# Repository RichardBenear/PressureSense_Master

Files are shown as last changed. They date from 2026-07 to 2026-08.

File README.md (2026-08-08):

# PressureSense

PressureSense_Master is the master controller for an irrigation pressure-monitoring and zone-scheduling system. It runs on a Seeed Studio XIAO ESP32-C6, reads a 0-100 PSI analog pressure sensor, schedules and runs sprinkler zones, and commands a pair of remote relay boards ("Yard" and "Field") over LoRa. A web UI served directly from the ESP32's SPIFFS partition provides live charting, schedule/zone configuration, a sprinkler-system map, and SD/SPIFFS file management. An on-board 3.5" SPI TFT mirrors live status, and a dedicated WebSocket feed drives a separate "Indoor unit" display.

## System overview

- **PressureSense_Master (this repo)** — the scheduler and LoRa master. Decides which zone should be active from the zone table, current pressure, and time of day; reads the pressure sensor; logs data to SD; serves the web UI; and commands the Yard/Field boards over LoRa.
- **Yard / Field remotes** (separate firmware - PressureSense_ValveNode) — dumb relay executors. They accept LoRa relay commands, switch outputs, run their own safety timers, and ACK/ERROR/STATUS back to the master (see [LoRa protocol](#lora-protocol) below).
- **Indoor unit** (separate client - PressureSense_Indoor) — connects to the master's `/ws` WebSocket and consumes the same `sensorUpdate`/`configData` JSON the CHART page uses, for a secondary indoor display (see [WebSocket protocol](#websocket-protocol) below).
- **PressureSense_App** — a Cloudflare Worker + Durable Object that relays that same `/ws` feed to the public internet. It never talks to the master directly; the **Indoor unit** acts as the bridge, holding one outbound connection to the master's local `/ws` and one outbound connection to this Worker's `/device` endpoint, forwarding frames in both directions. This repo has no code running on the master or the Indoor unit — it's purely the cloud side.

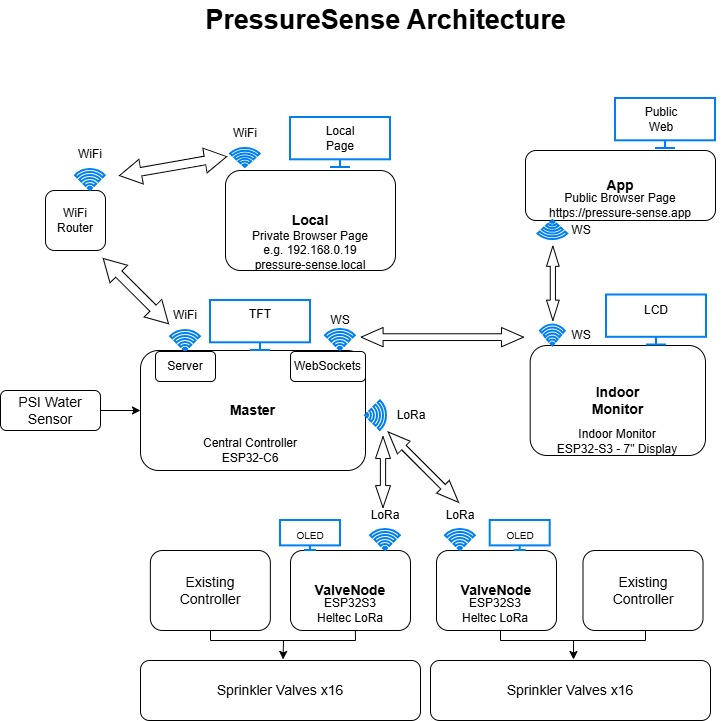
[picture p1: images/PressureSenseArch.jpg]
Architecture Diagram


## Hardware

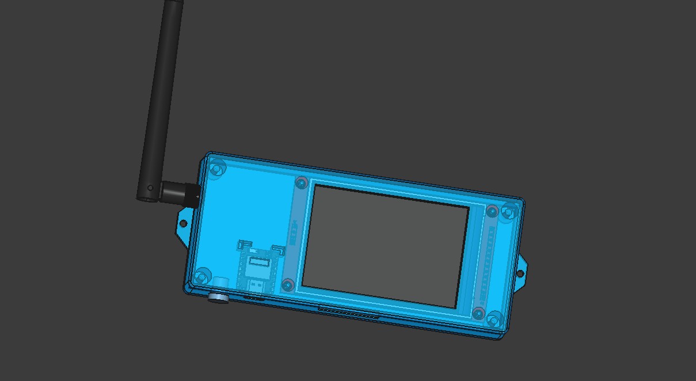
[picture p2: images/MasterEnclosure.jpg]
Enclosure
   
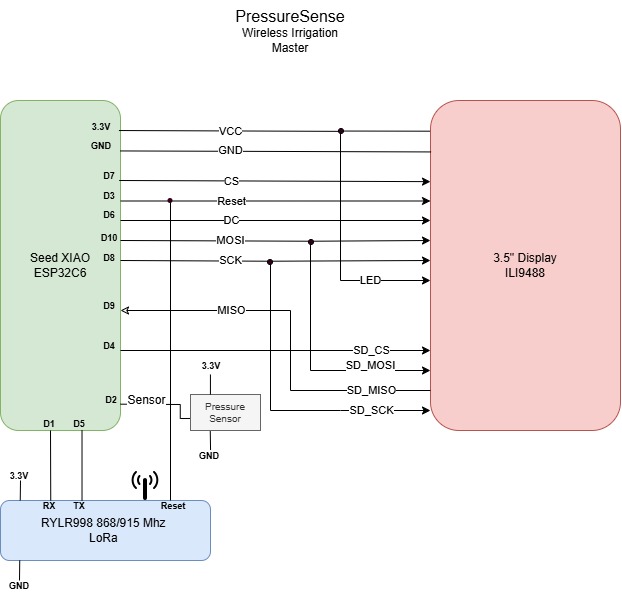
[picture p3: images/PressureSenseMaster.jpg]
Block Diagram
  

| Component | Notes |
| --- | --- |
| MCU | Seeed Studio XIAO ESP32-C6 |
| Pressure sensor | Analog, two-point calibrated (30 PSI @ 1.5V, 60 PSI @ 2.9V), sampled via `analogReadMilliVolts()` |
| Display | 3.5" SPI TFT, ILI9488 driver via LovyanGFX (`src/Display.h`/`.cpp`) |
| LoRa | RYLR998 module on `HardwareSerial1`, AT-command configured at boot |
| Storage | SD card (daily CSV data logs, plus original copies of calibration/weather files kept as a rollback, plus `water_waves.jpg` (background image, manually provisioned)) + SPIFFS (web UI, `site.json`/`controllers.json`, per-zone flow `calibration.json`, `weather_state.json`/`weather_cache.json`/`weather_log.json`, OTA partitions) |
| Enclosure | 3D-printable design in `FreeCAD/` (native `.FCStd` source) |

Pin assignments, sensor calibration constants, and LoRa radio parameters are all `#define`d near the top of [src/main.cpp](src/main.cpp).

## Web UI

Served from SPIFFS at the device's IP, or `http://pressure-sense.local/` via mDNS (Windows PCs need Apple's free [Bonjour Print Services](https://support.apple.com/kb/DL999) installed once for `.local` names to resolve — macOS and iOS support this natively). Five pages share `data/style.css`:

| Page | Files | Purpose |
| --- | --- | --- |
| CHART | `index.html` / `index.js` | Live pressure gauge, OK/WARN/HIGH/LOW status badge, scheduled-zone card, manual zone/program start-stop, a Runtime stat that shows "Wx Adj xx% / Deficit xx.x mm" underneath the active zone's minutes whenever weather auto-adjust is on, Highcharts pressure history (today or any saved day) with an optional ET0/precipitation weather overlay, status bar (location, sample rate, seasonal adjustments, zone delays, calibration offset) |
| CONFIG | `config.html` / `config.js` | Zone schedule editor: per-controller program cards (start time, day pips, duration, end time, overlap warning) with a popover to edit start/days/zone-delay/seasonal-adjustment; zones support drag-to-reorder, inline name/PSI/run editing with live-recalculated start times, add/delete. "Save Zone Config" saves only the schedule (to `controllers.json`, or a named seasonal preset); Location, Sensor Rate, and Weather Auto-Adjust settings each save independently to `site.json`; "Set as Active Schedule" promotes a loaded preset to be the live schedule |
| CALIB | `calibration.html` / `calibration.js` | Per-zone irrigation flow calibration (head specs + SVG-measured area → `mm_per_min`) with an editable Head Catalog, import from the `zone_calibration.py` script's output, and PSI calibration (moved here from CONFIG) |
| MAP | `map.html` / `map.js` | Renders the sprinkler layout SVG, highlights whichever zone(s) are currently active, full-yard or zoomed yard-only view with pan/zoom |
| FILES | `files.html` / `files.js` | Browse/delete SPIFFS and SD card files, preview JSON/text file contents, reboot the ESP32 |

CHART and MAP get live updates over Server-Sent Events at `/events`; the Indoor unit instead uses the JSON WebSocket at `/ws`.

## Key features

- **Zone scheduling** — `controllers.json` (a bare array: controllers → programs → zones) drives automatic activation; see [Zone schedule format](#zone-schedule-format) below.
- **Overlap detection** — the CONFIG page warns when two programs on the same controller share a day and their derived time windows intersect.
- **Manual control** — start/stop an individual zone or an entire lettered program (A-D) outside the schedule, each with its own run timer.
- **Seasonal adjustment** — a per-program percentage (`seasonal_adjust_pct`) that scales that program's scheduled run times up or down.
- **Zone-to-zone delay** — a per-program pause (`zone_delay_sec`) before a chained zone's relay turns on; it shortens that zone's own watering time and never shifts the nominal schedule.
- **Weather auto-adjust** — fetches daily ET0/precipitation from Open-Meteo, tracks a per-zone soil-water deficit, and scales each zone's run time (or skips a program entirely ahead of significant forecast rain) accordingly; enabled/tuned from the CONFIG page, with a 90-day history (`weather_log.json`) chartable on the CHART page.
- **Pressure calibration** — a one-point offset (entered as "actual PSI" against the live raw reading, computed client-side and persisted in `site.json`'s `psi_offset`) layered on top of the two-point factory calibration; set from the CALIB page.
- **Pressure status** — the CHART badge, the chart point colors, and the LoRa master itself (`buildPressureStatus()` in `main.cpp`, kept in sync with `updateStatStatus()` in `index.js`) all classify the live reading against the active zone's target PSI as OK / WARN / HIGH / LOW.
- **Simulation mode** — inject a fixed PSI value in place of the ADC reading, for testing the UI/alerts without water flowing.
- **Data logging** — one CSV per day on the SD card; CHART loads the current day live or any historical day from the file picker.
- **OTA updates** — ElegantOTA, mounted on the same web server.
- **All-off safety** — `ALL_OFF` is sent to both remotes before every zone transition.
- **Pressure vs. schedule state** — zone relay control (`serviceRemoteZoneControl()`), weather auto-adjust's water-applied accumulators, and the deviation alert are all driven by the schedule (`checkActiveZone()`'s `zoneNumber`/`zoneAvgPsi`, and `manualZoneRuns[]` for manual runs), not by pressure. `ZONES_ALL_OFF_PSI`/`currentPressure` only drive the informational `allOff` field broadcast over `/ws` and the TFT gauge's color threshold. (These used to also gate the items above — pressure on this system's tank setup snaps to ~62 PSI on a refill and takes hours to decay back down, so requiring PSI to first drop below `ZONES_ALL_OFF_PSI` could delay, or with a tight enough schedule entirely skip, turning a zone's relay on. Fixed — see git history.)

## Zone schedule format

`data/controllers.json` is the single source of truth for irrigation scheduling — a bare array, read directly by the firmware (`checkActiveZone()` in `main.cpp`) and edited on the CONFIG page. Site identity, sensor rate, PSI calibration, and weather/auto-adjust settings live separately in `data/site.json`; the CONFIG page's `/load-zone-table` endpoint recombines both files into one document for rendering, but they're saved independently (schedule via `/submit-zone-form`, site settings via `/submit-site-form`):

```json
[
  {
    "id": "yard",
    "name": "Yard",
    "programs": [
      {
        "id": "A",
        "days": [0, 1, 2, 3, 4, 5, 6],
        "start": "05:00",
        "zone_delay_sec": 0,
        "seasonal_adjust_pct": 0,
        "zones": [
          { "znumber": 1, "zname": "Garage", "avgpsi": 47, "run": 45 }
        ]
      }
    ]
  }
]
```

`site.json` holds the rest:

```json
{
  "name": "Silver Creek Ranch",
  "sensor_interval_sec": 30,
  "psi_offset": 0.0,
  "latitude": 43.6, "longitude": -116.6, "timezone": "America/Denver",
  "mm_per_min_default": 0.25,
  "weather": { "enabled": true, "auto_adjust": true, "reference_deficit_mm": 6.0, "max_deficit_mm": 25.0, "max_adjust_pct": 150, "min_adjust_pct": 0, "rain_skip_threshold_mm": 6.0 }
}
```

- `days` is an integer array, `0` = Sunday … `6` = Saturday.
- A zone's actual start time is **derived**, never stored: the first zone in a program starts at the program's `start`; every later zone starts when the previous one's `run` ends. `zone_delay_sec` only pauses that zone's relay turn-on — it shortens the zone's own watering time and never shifts this schedule.
- `seasonal_adjust_pct` and `zone_delay_sec` live on the program, not per zone.
- The CONFIG page's "Load External"/"Save As" mechanism supports named schedule presets (e.g. `controllers_spring.json`, `controllers_summer.json`) alongside the live `controllers.json` — "Set as Active Schedule" promotes whichever preset is currently loaded/edited to be the live schedule.

## LoRa protocol

The master and the Yard/Field ValveNode remotes are separate firmware projects (this repo and `PressureSense_ValveNode`) that speak a shared wire protocol over LoRa. This section documents that protocol from the master's side (`initLoRa()`, `sendLoraPacket()`/`sendLoraRelayOn()`, `handleLoraReceiveLine()` in `src/main.cpp`); see `PressureSense_ValveNode/README.md` for the relay-side implementation (RadioLib/SX1262 radio driver, packet CRC verification, per-zone run timers, master-silence watchdog). This repo is the source of truth for the wire format; that repo is the source of truth for how the relay board executes it.

### Radio link

The master uses a **RYLR998** module (AT-command firmware over `HardwareSerial1`, TX/RX on `D5`/`D1`), configured at boot in `initLoRa()`. The ValveNode remotes use a different chip (SX1262 via RadioLib), but both sides are set to the same over-the-air parameters so they can talk to each other:

| Parameter | Value |
| --- | --- |
| Frequency | 915 MHz |
| Spreading factor | 8 |
| Bandwidth | 125 kHz |
| Coding rate | 4/5 |
| Preamble | 8 symbols |
| TX power | 14 dBm |
| Network ID | 18 |

| Node | LoRa address |
| --- | --- |
| Master (this repo) | 10 |
| Yard | 1 |
| Field | 2 |

Outbound packets are sent via the RYLR998's `AT+SEND=<address>,<length>,<hex-payload>` command; inbound packets arrive as `+RCV=<address>,<length>,<hex-payload>,<rssi>,<snr>` lines that `handleLoraReceiveLine()` parses.

### Packet structure

```
[Command/Status] [Relay#/Status] [Flags] [Payload...] [CRC-H] [CRC-L]
      1 byte           1 byte      1 byte    N bytes    1 byte  1 byte
```

The first 3 bytes are a fixed header; everything after is variable-length payload, followed by a 2-byte application-level CRC-16/CCITT (polynomial `0x1021`, initial value `0xFFFF`, computed over every preceding byte) — separate from the LoRa radio's own over-the-air frame integrity check, which the RYLR998/RadioLib handle transparently underneath this.

**Commands (Master → ValveNode)**, sent by `sendLoraPacket()` / `sendLoraRelayOn()`:

| Code | Name | Payload | Relay byte |
| --- | --- | --- | --- |
| 0x01 | RELAY_ON | `minutes` (0-255, 0 = no timer) + `len` + zone name (ASCII, up to 20 chars) | Relay number (1-16) |
| 0x02 | RELAY_OFF | none | Relay number |
| 0x04 | ALL_OFF | none | 0 |
| 0x05 | STATUS_REQUEST | none | 0 |
| 0x06 | RESET | none | 0 |

`ALL_OFF` is sent to both Yard and Field before every scheduled zone transition and when stopping all zones (`sendLoraAllOffToRemotes()`); `RELAY_ON` carries the run-time timer and zone name directly (older 0x03/0x08 follow-up commands are retired).

**Responses (ValveNode → Master)**, handled by `handleLoraReceiveLine()`:

| Code | Name | Payload |
| --- | --- | --- |
| 0x80 | ACK | none |
| 0x81 | ERROR | error code byte |
| 0x82 | STATUS | 2 bytes: relay state bitmask |

The master verifies each response's CRC and logs ACK/ERROR/STATUS to serial for diagnostics — it does not currently retry on a missing ACK or track sequence numbers, so a dropped response is only visible in the serial log, not surfaced to the schedule logic.

**Flags byte:**

| Bit | Name | Meaning |
| --- | --- | --- |
| 0 | `LORA_FLAG_CRC` | Packet includes the trailing CRC-16 (always set) |
| 1 | `LORA_FLAG_RESPONSE_REQUIRED` | Sender expects an ACK/ERROR response (always set) |
| 2 | `LORA_FLAG_TARGET_FIELD` | Yard and Field share one LoRa channel — 0 targets Yard, 1 targets Field. Set automatically from the destination address by `loraFlagsForAddress()`. |
| 3-7 | Reserved | |

### Protocol example

Master turns on relay 3 for 5 minutes, named "Front Lawn", targeting Yard:

```
0x01 0x03 0x03 0x05 0x0A "Front Lawn" 0xXX 0xXX
 cmd  rly flg  min  len     name       CRC-H/L
```

(`flags = 0x03` = `LORA_FLAG_CRC | LORA_FLAG_RESPONSE_REQUIRED`, targeting Yard since bit 2 is 0), sent as `AT+SEND=1,<len>,<hex>`.

ValveNode responds:

```
0x80 0x00 0x03 0xXX 0xXX   // ACK, status 0, relay 3
```

## WebSocket protocol

The master serves one WebSocket endpoint, `/ws`, consumed by two sibling repos: **PressureSense_Indoor** (a touchscreen client with a direct LAN connection) and, through that same Indoor unit acting as a bridge, **PressureSense_App** (a Cloudflare Worker that fans the feed out to remote browsers and relays a narrow set of commands back in — the Worker has no path to the master except through that bridge). This section documents the wire format from the master's side (`buildSensorUpdateJson()`, `buildConfigDataJson()`, `buildManualZoneRunsJson()`, `onWsEvent()` in `src/main.cpp`); see those repos' own READMEs for how each client consumes it and where they deliberately depart from the master's own behavior.

### Server → client messages

Sent via `ws.textAll()` (broadcast to every connected client) or `client->text()` (just the requester), depending on the row below:

| `type` | When sent | Notes |
| --- | --- | --- |
| `sensorUpdate` | Broadcast every sample cycle (`sensorRateSec`); also sent to a client alone right after `WS_EVT_CONNECT` if a reading already exists | Live PSI + active-zone/schedule snapshot — see field reference below |
| `manualZoneStatus` | Broadcast after any `manualZone`/`manualProgram` command changes a run, and every sample cycle | Current manual/program runs — see field reference below. Deliberately kept out of `sensorUpdate` |
| `configData` | To the requester, reply to `getConfig` | `location`, `sampleRateSec`, `calibOffset`, `zones` (the same combined site+controllers document the CONFIG page loads over HTTP — see [Zone schedule format](#zone-schedule-format)) |
| `fileList` | To the requester, reply to `getFiles` | `sdFiles` / `spiffsFiles` arrays |
| `schedule` | To the requester, reply to `getSchedule` | `controllers` — `controllers.json` contents only, never `site.json`/`psi_offset` |
| `schedulesEnabled` | To the requester, reply to `getSchedulesEnabled`; also broadcast to every client after `setSchedulesEnabled` | `enabled` bool |
| `weatherState` | To the requester, reply to `getWeatherState` | Same shape as `GET /weather-state` (firmware-owned runtime deficit/adjust-pct/skip state) plus `type` |
| `weatherLog` | To the requester, reply to `getWeatherLog` | Same shape as `GET /weather_log.json` (`log` array, up to 90 days) plus `type` |
| `weatherCache` | To the requester, reply to `getWeatherCache` | Same shape as `GET /weather_cache.json` (raw Open-Meteo response) plus `type` |
| `calibration` | To the requester, reply to `getCalibration` | Same shape as `GET /calibration.json` (`zones` array) plus `type` |
| `weatherSettings` | To the requester, reply to `getWeatherSettings` | Narrow, read-only subset of `site.json`'s `weather` block (`auto_adjust`, `reference_deficit_mm`, `max_deficit_mm`, `rain_skip_threshold_mm`, `min_adjust_pct`, `max_adjust_pct`, `mm_per_min_default`) — never the full `site.json` |
| `ack` | To the requester, reply to `saveZones`, `deleteFile`, `reset`, `saveSchedule`, `setSchedulesEnabled`, `manualZone`, `manualProgram` | `{cmd, success, message}` (`sendWsAck()`) — `cmd` echoes back which command it's acknowledging |

### Client → server commands

Sent as `{"cmd": "...", ...}`; dispatched in `onWsEvent()`'s `WS_EVT_DATA` case:

| `cmd` | Fields | Effect |
| --- | --- | --- |
| `getConfig` | — | Replies with `configData` |
| `getFiles` | — | Replies with `fileList` |
| `getSchedule` | — | Replies with `schedule` |
| `saveSchedule` | `controllers` | Overwrites `controllers.json` only; acked |
| `getSchedulesEnabled` | — | Replies with `schedulesEnabled` |
| `setSchedulesEnabled` | `enabled` | Pause/resume automatic scheduling; acked to the requester, then `schedulesEnabled` broadcast to all clients |
| `getWeatherState` | — | Replies with `weatherState` |
| `getWeatherLog` | — | Replies with `weatherLog` |
| `getWeatherCache` | — | Replies with `weatherCache` |
| `getCalibration` | — | Replies with `calibration` |
| `getWeatherSettings` | — | Replies with `weatherSettings` |
| `manualZone` | `action` (`start`/`stop`/`stopall`), `controller`, `znumber`, `run` | Start/stop a manual zone run; acked, then `manualZoneStatus` broadcast to all clients |
| `manualProgram` | `action` (`start`/`stop`/`next`), `controller`, `program` | Start/stop/advance a manual lettered-program run; acked, then `manualZoneStatus` broadcast to all clients |
| `saveZones` | `zones: {site, weather, controllers}` | Legacy combined site+controllers save in one command; acked. Not used by the current web UI (which saves over HTTP via `/submit-site-form`/`/submit-zone-form` instead) — kept for any future WS-only client |
| `deleteFile` | `source` (`spiffs`/`sd`), `filename` | Deletes a file; acked |
| `reset` | — | Acks, then reboots the ESP32 |

Only `getSchedule`, `saveSchedule`, `getSchedulesEnabled`, `setSchedulesEnabled`, `manualZone`, `manualProgram`, `getWeatherState`, `getWeatherLog`, `getWeatherCache`, `getCalibration`, and `getWeatherSettings` are ever relayed from a remote browser through PressureSense_App and the Indoor unit back to the master — `getConfig`/`getFiles`/`saveZones`/`deleteFile`/`reset` are only reachable from a client with a direct LAN connection to `/ws`.

### `sensorUpdate` field reference

| Field | Type | Notes |
| --- | --- | --- |
| `psi` | float | Calibrated live pressure (1 decimal) |
| `rawPsi` | float | Pressure before the calibration offset |
| `sampleRateSec` | int | Current sample interval, seconds |
| `adcVoltage` | float | Raw ADC voltage behind the reading (3 decimals) |
| `zoneNumber` | string | Active zone ID; `"0"` means all zones off |
| `zoneName` | string | Active zone's human-readable name |
| `zoneAvgPsi` | float | Active zone's target PSI |
| `status` | string | `OK` / `WARN` / `HIGH` / `LOW`, from `buildPressureStatus()` (mirrors `updateStatStatus()` in `data/index.js`) |
| `controller` | string | `Yard` \| `Field` \| `OFF` |
| `days` | string | Active-days abbreviation, e.g. `"Mo We Fr"`, or `"NONE"` when idle (`formatDaysForDisplay()`) |
| `start` | string | Scheduled start `"HH:MM"`; `"00:00"` means no fixed start |
| `run` | string | Runtime in minutes |
| `remaining` | string | Minutes left in the active run, e.g. `"12m"` (`getZoneRemainingMinutes()`); `""` when not computable |
| `mapKey` | string | `lower(controller):zoneNumber`, e.g. `"yard:3"` (`buildMapKey()`) — matches the MAP page's zone-coverage keys |
| `allOff` | bool | `true` when `currentPressure >= ZONES_ALL_OFF_PSI` (59 PSI) |
| `simMode` | bool | `true` while simulation mode is injecting a synthetic PSI reading |
| `weatherAutoAdjustEnabled` | bool | `site.json`'s `weather.auto_adjust` setting — gates whether `weatherAdjustPct`/`deficitMm` below are meaningful. Also the top-level gate the CHART page's Runtime stat uses to show/hide its "Wx Adj / Deficit" sub-line |
| `weatherAdjustPct` | int | Active zone's live weather adjustment percentage (100 = neutral) — same value already folded into `run` above, surfaced separately so clients can show it alongside the adjusted minutes |
| `deficitMm` | float | Active zone's current soil-water deficit (mm), from `weather_state.json` — diagnostic, shown regardless of `weatherAutoAdjustEnabled`'s effect on scheduling, but the UI only displays it when that flag is true |
| `time` / `date` | string | Wall clock at the master |
| `location` | string | Site label from `site.json` |

**Don't key idle/active-zone logic off `allOff`.** It's only the informational pressure-recovery heuristic described in [Key features](#key-features) above — on this system's pressure-tank setup a refill snaps to ~62 PSI and takes hours to decay back down, so `allOff` reads "not idle" for most of a normal idle cycle. Every downstream client (Indoor, PressureSense_App) keys idle/active-zone state off `zoneNumber`/`controller` (or an empty `manualZoneStatus` runs list) instead — both had this exact bug at one point, found and fixed by auditing every repo for the same `allOff` dependency. Only the master's own PSI gauge color threshold still legitimately uses it.

### `manualZoneStatus` field reference

Sent as `{"type":"manualZoneStatus","weatherAutoAdjustEnabled":bool,"runs":[...]}` (`buildManualZoneRunsJson()`). `weatherAutoAdjustEnabled` is the same site-wide `weather.auto_adjust` flag `sensorUpdate` carries, included here too since this is a separate message a client could receive first. Each entry in `runs`:

| Field | Type | Notes |
| --- | --- | --- |
| `controller` | string | `Yard` / `Field` |
| `relay` | int | Relay/zone number |
| `remainingSec` | int | Seconds left in the current zone's run |
| `totalRunMinutes` | int | That zone's configured run length |
| `program` | bool | `true` if this run is part of a lettered program rather than a single manual zone |
| `programLetter` | string | Program letter (A-D) when `program` is true, else empty |
| `weatherAdjustPct` | int | This zone's live weather adjustment percentage — only meaningful when `program` is true. A manual **zone** run uses exactly the minutes the user picked, bypassing weather adjustment entirely (`startManualZoneRun()`), so this is neutral/100 for those; a manual **program** run replays the schedule's own per-zone adjustment (`findNextProgramZone()`), so it's real here |
| `deficitMm` | float | This zone's current soil-water deficit (mm) — same caveat as `weatherAdjustPct` above |

A run is left out of `runs` while it's paused between zones during a zone-to-zone delay (`delayPending`), not just once it ends.

## Data log format

One row per sample, appended to a daily CSV on the SD card (filename from `generateDailyFilename()`):

```
readingID,date,time,psi,zoneNumber,zoneAvgPsi
```

## HTTP API

All routes are registered in `setup()` in `src/main.cpp`. Static assets (the `data/` folder) are served directly from SPIFFS at `/` — except `/water_waves.jpg`, which is served from the SD card by an explicit route instead (see table below); it was moved out of `data/`/SPIFFS because at 221KB it was consuming a large share of the mostly-full SPIFFS partition.

| Endpoint | Method | Purpose |
| --- | --- | --- |
| `/get-data-file` | GET | Fetch a CSV log file by name |
| `/water_waves.jpg` | GET | Background image for all 5 pages' `body.ag-page::before` CSS layer — served from the SD card (not SPIFFS) via the same locked/chunked pattern as `/get-data-file`; 404s cleanly if the SD card hasn't been provisioned with the file yet |
| `/get-daily-filename` | GET | Current day's log filename |
| `/list-sd-card-files`, `/list-spiffs-files`, `/list-json-files` | GET | File listings for the FILES page |
| `/get-spiffs-json-file` | GET | Read a JSON file from SPIFFS |
| `/delete-file` | GET | Delete a file from SD or SPIFFS |
| `/load-zone-table`, `/load-sd-zone-table` (compat alias), `/load-spiffs-zone-table?filename=` | GET | `site.json` + `controllers.json` recombined into one document for the CONFIG page (see [Zone schedule format](#zone-schedule-format)); `/load-spiffs-zone-table` also serves a named schedule preset or any other SPIFFS `.json` by filename |
| `/submit-zone-form?filename=` | POST | Save only the schedule — to `controllers.json` by default, or a named preset (e.g. `controllers_summer.json`) if `filename` is given |
| `/submit-site-form` | POST | Save site identity, sensor rate, and weather/auto-adjust settings to `site.json` (independent of the schedule save) |
| `/submit-calib-offset` | POST | Save just the PSI calibration offset to `site.json` (CALIB page) |
| `/calibration.json`, `/submit-calibration-form` | GET / POST | Per-zone flow calibration (`mm_per_min`, head specs, SVG area) — CALIB page |
| `/weather-state`, `/weather_cache.json`, `/weather_log.json` | GET | Firmware-computed weather auto-adjust state, the last raw Open-Meteo response, and the 90-day deficit/adjustment history |
| `/weather-fetch-now` | GET | Queue an on-demand weather fetch (runs on the next `loop()` tick, not inline, to avoid blocking the request task) |
| `/get-schedules-enabled`, `/set-schedules-enabled` | GET / POST | Pause / resume automatic scheduling |
| `/manual-zones` | GET | Current manual zone/program run status |
| `/manual-zone`, `/manual-program` | POST | Start/stop a manual zone or lettered program; `/manual-program` also takes `action: "next"` to skip a running program straight to its next zone (or stop it, if the current zone is the last one) |
| `/set-sim-pressure`, `/clear-sim` | GET | Enable / disable simulation mode |
| `/sd-usage` | GET | SD card usage + WiFi/uptime, for page footers |
| `/spiffs-usage` | GET | SPIFFS usage (total/used/free/percent) — added to diagnose SPIFFS filling up and causing save failures; check this before adding any new file to `data/` |
| `/ping` | GET | Lightweight health check: uptime, heap stats, WS client count |
| `/reset` | GET | Reboot the ESP32 |
| `/events` | SSE | Live `new-readings` push for CHART/MAP |
| `/ws` | WebSocket | `sensorUpdate` / `configData` / `manualZoneStatus` JSON feed + command interface for the Indoor unit and (via its relay bridge) PressureSense_App — see [WebSocket protocol](#websocket-protocol) below |

## Getting started

1. **Secrets** — copy `include/secrets.example.h` to `include/secrets.h` and fill in your WiFi SSID/password. `include/secrets.h` is git-ignored.
2. **Build & flash firmware**:
   ```
   pio run --target upload
   ```
3. **Upload the web UI** (everything in `data/`) to SPIFFS:
   ```
   pio run --target uploadfs
   ```
4. **Monitor serial output**:
   ```
   pio device monitor
   ```
5. Visit `http://pressure-sense.local/` (mDNS) or the IP address printed on boot. **Windows users:** `.local` hostnames aren't resolved by Windows out of the box — install Apple's free [Bonjour Print Services](https://support.apple.com/kb/DL999) once, or just use the IP address shown on the TFT/serial log. macOS and iOS resolve `.local` natively, no install needed.

Subsequent firmware updates can go over the air via ElegantOTA at `<device-ip>/update` once the device is reachable on WiFi.

### Boot sequence (serial log markers)

```
[1]  TFT display init
[1b] LoRa radio init (RYLR998 AT config)
[2]  WiFi connect + mDNS (pressure-sense.local)
[3]  SPIFFS mount
[4]  SD card mount
[5]  NTP time sync
[6]  Daily log file + saved location
[7]  Web server + OTA started
```

## Project structure

```
src/main.cpp            Firmware: WiFi/SPIFFS/SD/NTP setup, sensor reads, scheduling,
                         LoRa master protocol, HTTP/WS/SSE server, OTA
src/Display.h/.cpp      LovyanGFX TFT UI (mirrors the web CHART page on-device)
include/secrets.h       WiFi credentials (git-ignored; see secrets.example.h)
data/                   Web UI served from SPIFFS -- index/config/calibration/map/files .html + .js, style.css
data/zone-utils.js      Shared schedule math (derived start/end times, day-array matching,
                         overlap detection) used by both config.js and index.js
data/site.json          Site identity/sensor-rate/calibration/weather config -- checked in as the
data/controllers.json   default seed data so a fresh flash ships a working setup instead of an
                         empty one (see Zone schedule format above); overwritten by whatever you
                         save from the CONFIG page afterward
data/controllers_spring.json   Seasonal schedule presets -- starting points to customize via the
data/controllers_summer.json   CONFIG page's Load External/Save As, then "Set as Active Schedule"
data/controllers_fall.json     to make one live
calib/                  Zone flow calibration tooling: zone_calibration.py's own output
                         (zone_calibration.json/.txt), independent of the device's calibration.json
reference/               Git-tracked copies of files that actually live on the device's SD card
                         or SPIFFS in production, kept here as a safety net since there's no
                         automated way to regenerate/redeploy them (unlike data/ -> SPIFFS via
                         `pio run --target uploadfs`).
reference/weather_log.json     Sample of the 90-day weather deficit/adjustment history.
reference/water_waves.jpg      Background image for style.css's body.ag-page::before layer.
                         NOT in data/ (SPIFFS) -- served from the SD card instead via the
                         /water_waves.jpg route (src/main.cpp), because at 221KB it was the
                         largest single file in data/ and was pushing SPIFFS to ~96% full,
                         which was failing schedule saves. Must be manually copied to the SD
                         card's root as water_waves.jpg after any SD card swap/reformat -- there
                         is no automated deploy path for it. Do not move this file back into
                         data/ without addressing SPIFFS headroom first -- check current usage
                         via GET /spiffs-usage.
scripts/zone_calibration.py     Computes per-zone mm_per_min from head specs + SVG-measured area
scripts/dxf_to_svg.py           Converts a QCAD/AutoCAD DXF sprinkler drawing to SVG for the MAP page
scripts/remove_qcad_trial.py    Strips QCAD trial-version watermark artifacts from exported SVGs
docs/                   Architecture reference diagram (PressureSenseMaster.drawio.png)
FreeCAD/                Enclosure CAD source (enclosure.FCStd)
images/                 Reference photos
platformio.ini          Board/framework/library config (seeed_xiao_esp32c6, Arduino framework)
partitions.csv          Custom partition table (dual OTA app slots + SPIFFS)
```

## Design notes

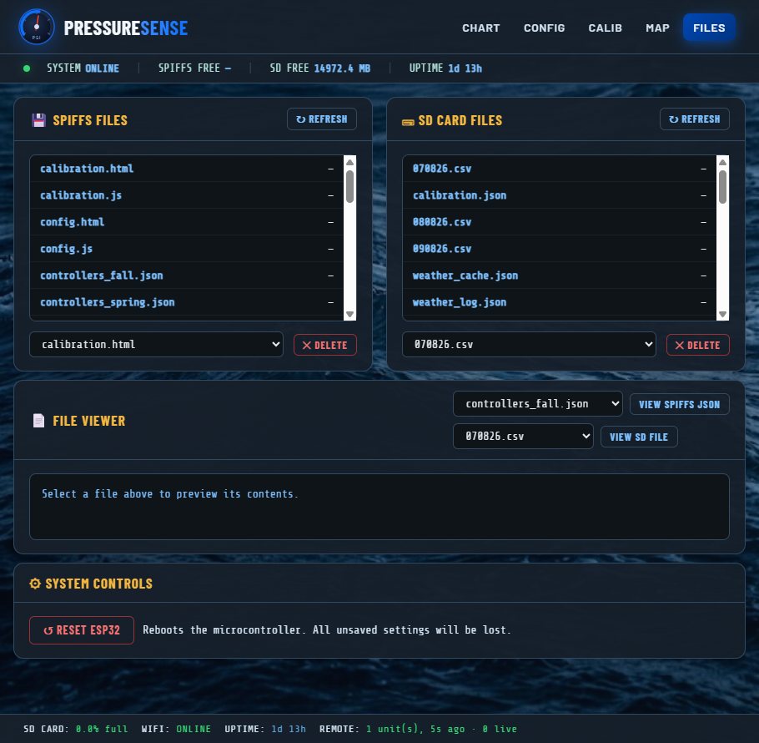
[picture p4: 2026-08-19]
images/PressureSenseFileManagement.jpg

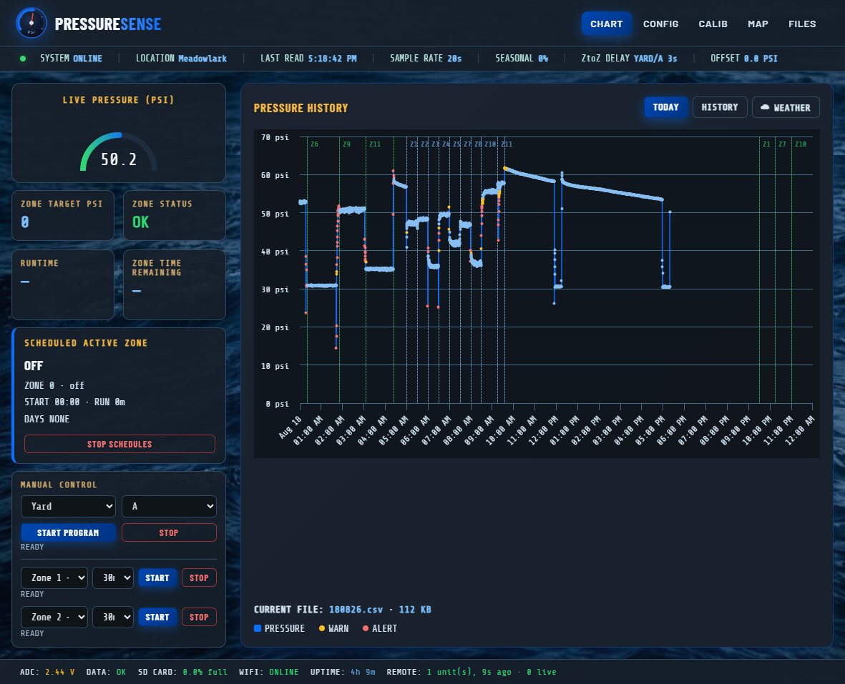
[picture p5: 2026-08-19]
images/PressureSenseChart.jpg

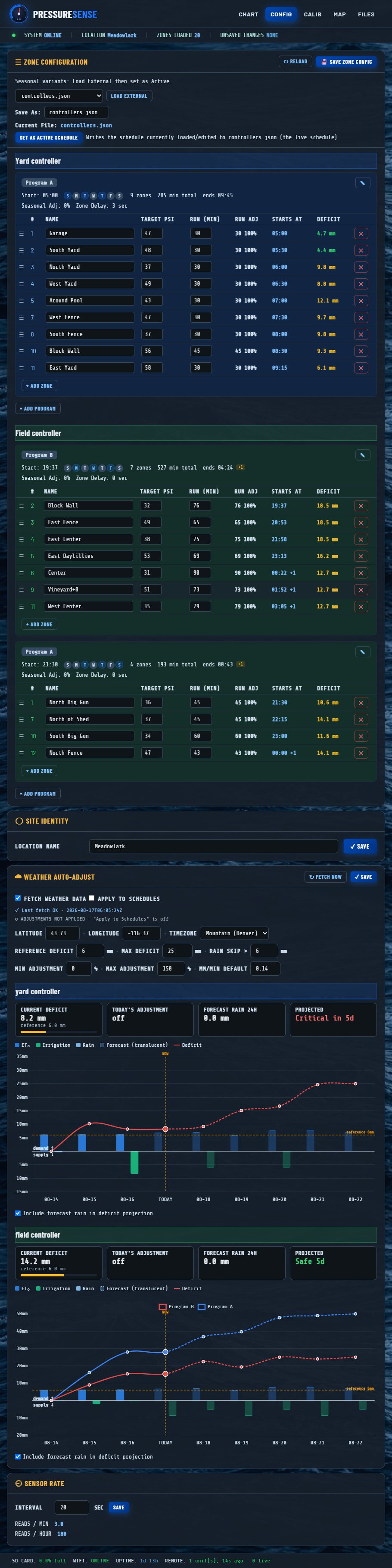
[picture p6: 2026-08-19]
images/PressureSenseConfiguration.jpg

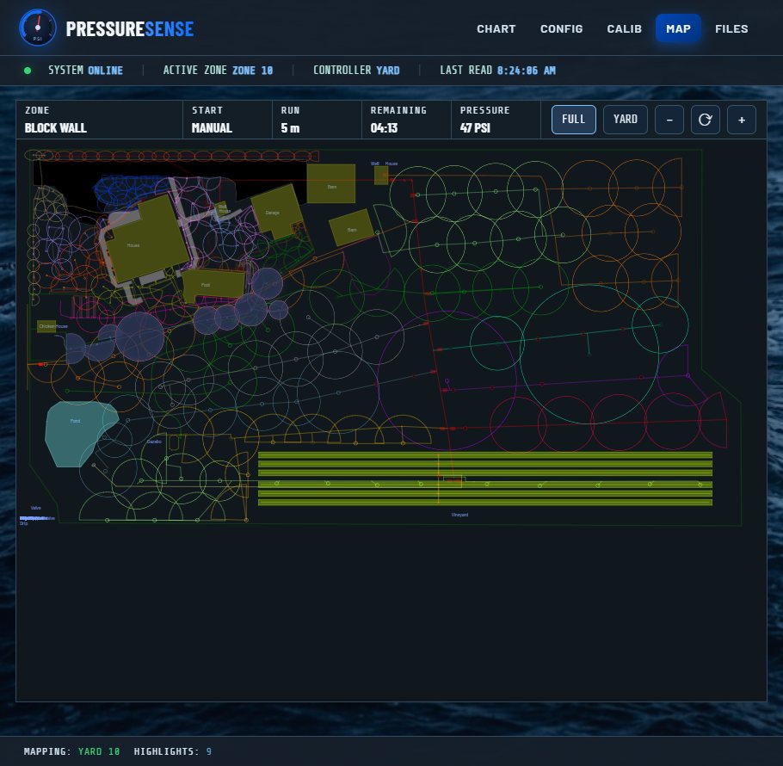
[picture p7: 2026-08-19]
images/PressureSenseZoneMap.jpg

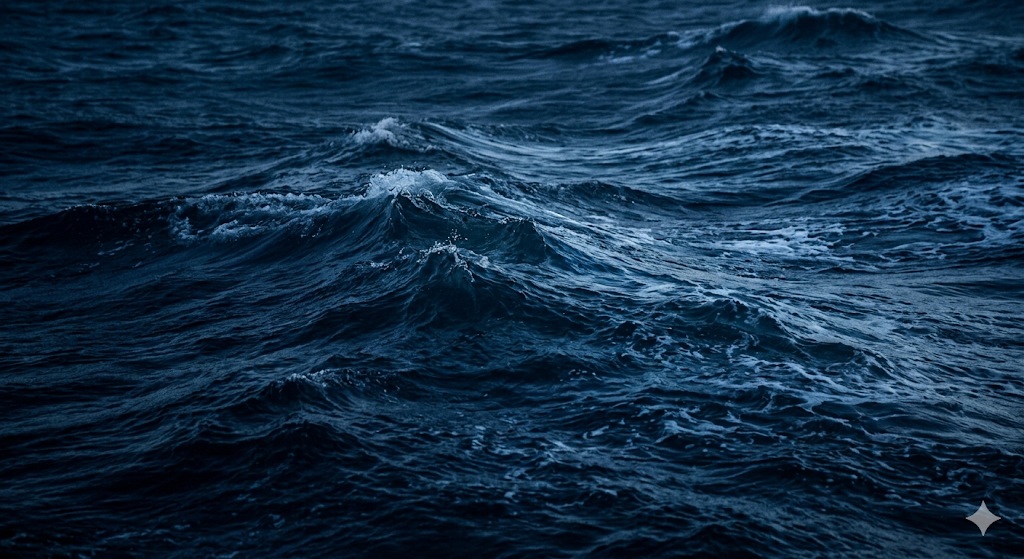
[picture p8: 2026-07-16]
reference/water_waves.jpg

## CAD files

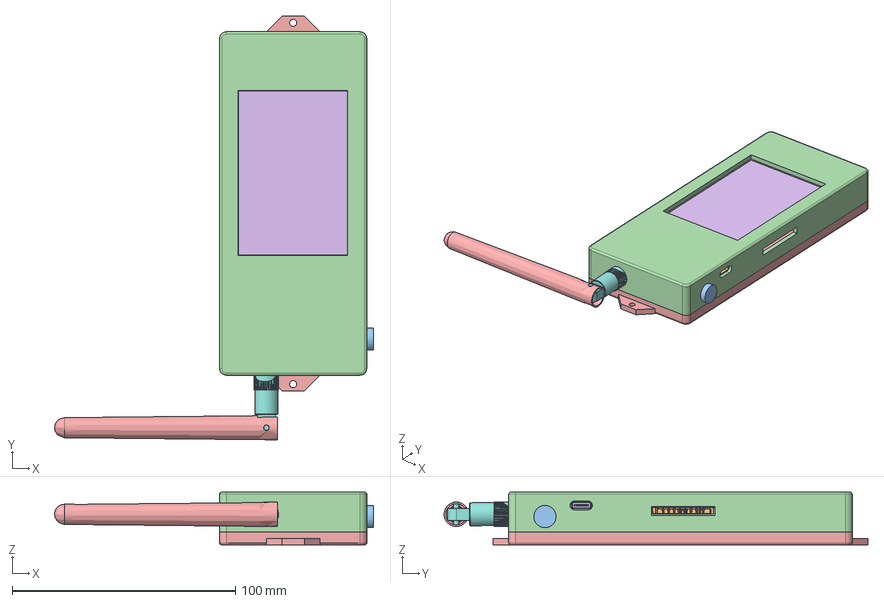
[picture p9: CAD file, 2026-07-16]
FreeCAD/enclosure.FCStd
143.0 x 190.0 x 23.7 mm
3.5 LCD TFT Module - Without Glass
0603 Resistor
0603 Capacitor
3.5 LCD TFT Screen without glass
Screen
0603 Resistor001
0603 Resistor002
0603 Resistor003
0603 Resistor004
SOT23-3
SOT23-004
0603 Resistor005
0603 Capacitor001
0603 Resistor006
BOSS-EXTRUDE14_8_
BOSS-EXTRUDE7_4_
BOSS-EXTRUDE7_3_
BOSS-EXTRUDE14_4_
BOSS-EXTRUDE14_2_
BOSS-EXTRUDE14_11_
BOSS-EXTRUDE7_7_
BOSS-EXTRUDE14_9_
BOSS-EXTRUDE14_3_
BOSS-EXTRUDE14_7_
MIRROR2
BOSS-EXTRUDE14_5_
BOSS-EXTRUDE14_12_
BOSS-EXTRUDE7_8_
BOSS-EXTRUDE7_1_
BOSS-EXTRUDE14_10_
BOSS-EXTRUDE7_9_
BOSS-EXTRUDE14_6_
BOSS-EXTRUDE14_1_
BOSS-EXTRUDE7_6_
BOSS-EXTRUDE7_2_
CUT-EXTRUDE5
BOSS-EXTRUDE7_5_
U.FL Connector v1
U.FL Connector v002
U.FL Connector v003
Shield
SKTAAAE010 v1
SKTAAAE010 v002
KH5220-A36 (Ceramic Antenna) v2
KH5220-A36 (Ceramic Antenna) v003
KH5220-A36 (Ceramic Antenna) v004
KH5220-A36 (Ceramic Antenna) v005
ant
ant001
ant002
conn_body
SMA_threads
socket
PowerJack
Bottom
Lid002

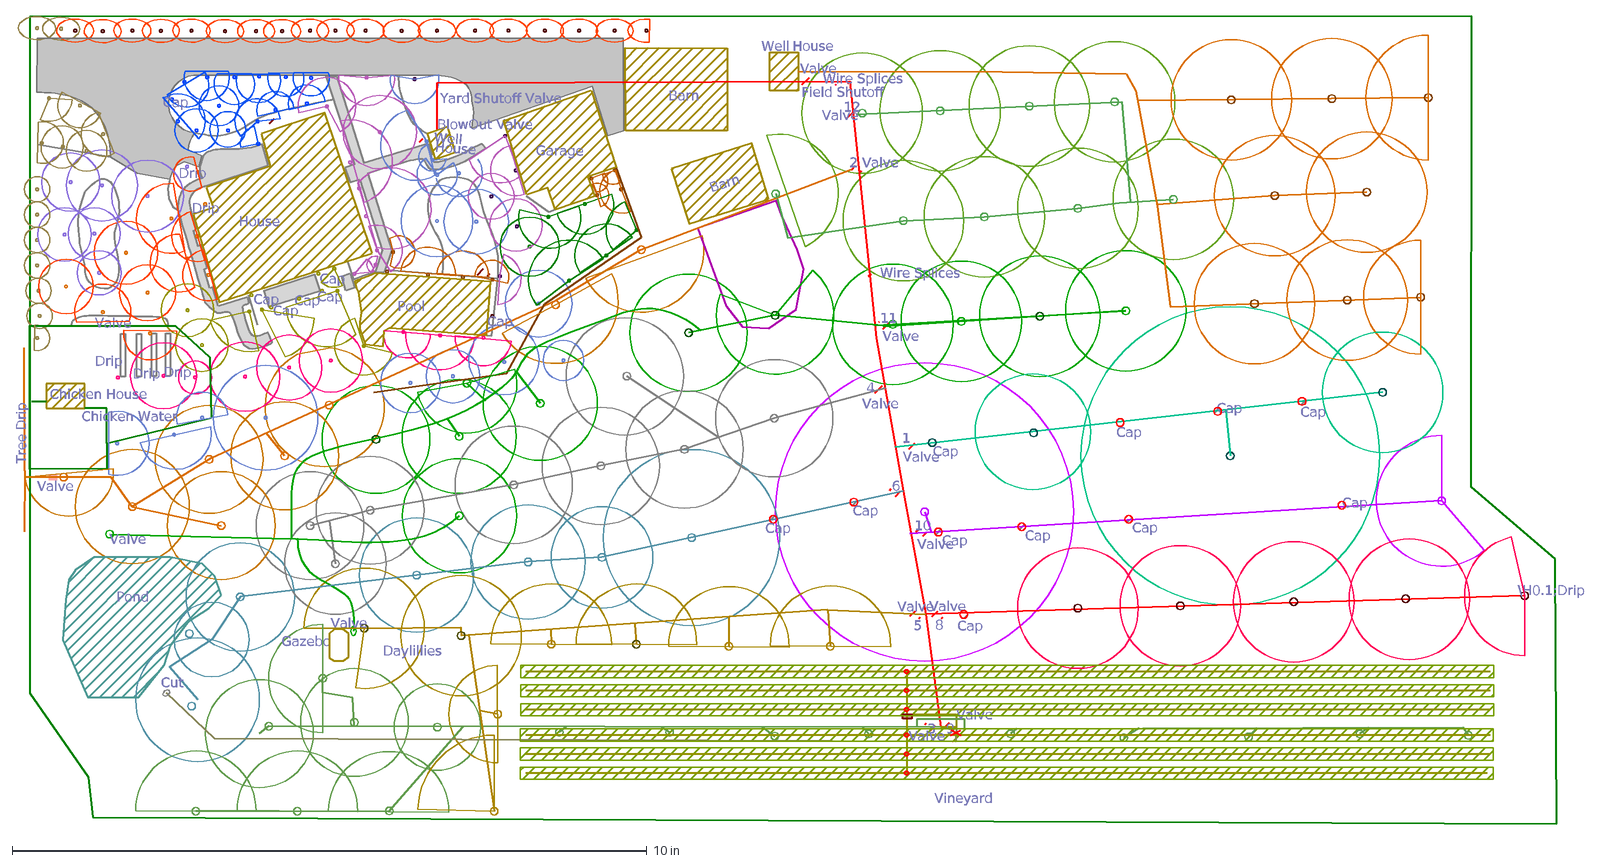
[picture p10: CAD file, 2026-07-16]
images/sprinkler_mapVer8.dxf
House
Pool
Garage
Barn
Chicken House
Pond
Well
Vineyard
Gazebo
Daylillies
Cut
Valve
Field Shutoff
Yard Shutoff Valve
BlowOut Valve
Tree Drip
Wire Splices
\H0.1;Drip
2
12
11
4
1
6
10
5
8
3
9
Cap
Drip
Chicken Water

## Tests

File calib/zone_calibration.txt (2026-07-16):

==================================================================================================================================
                                                   Zone Irrigation Calibration                                                    
                               SVG: ..\images\sprinkler_mapVer8.svg   Scale: 24.01 x 26.03 ft/unit                                
==================================================================================================================================
Ctrl     Zone  Name               Area ft²   Acres    PSI   Flow GPM    mm/min  Head / Emitter          Layers
----------------------------------------------------------------------------------------------------------------------------------
Field       1  North Big Gun        14,263   0.327     36      40.25   0.11497  Big Gun x1              f_cov_1
Field       2  Block Wall            9,704   0.223     32       4.22   0.01770  Rotor x1                f_cov_2
Field       3  East Fence            7,100   0.163     49       5.22   0.02994  Rotor x1                f_cov_3
Field       4  East Center          12,491   0.287     38       4.59   0.01499  Rotor x1                f_cov_4
Field       5  East Daylillies       7,753   0.178     53       5.43   0.02851  Rotor x1                f_cov_5
Field       6  Center               12,201   0.280     31       4.15   0.01386  Rotor x1                f_cov_6
Field       7  North of Shed        14,887   0.342     37       4.53   0.01241  Rotor x1                f_cov_7
Field       9  Vineyard+8           18,743   0.430     51      30.56   0.06643  Drip + Pop-up x5 †      f_cov_8, f_cov_9
Field      10  South Big Gun        12,327   0.283     34      39.12   0.12928  Big Gun x1              f_cov_10
Field      11  West Center          17,018   0.391     35       4.41   0.01056  Rotor x1                f_cov_11
Field      12  North Fence          12,365   0.284     47       5.11   0.01684  Rotor x1                f_cov_12
Yard        1  Garage                2,645   0.061     47       5.11   0.07871  Rotor x1                yd_cov_garage_south, yd_cov_garage_east
Yard        2  South Yard            5,378   0.123     48       5.16   0.03912  Rotor x1                yd_cov_south, yd_cov_se
Yard        3  North Yard            4,562   0.105     37       4.53   0.04049  Rotor x1                yd_cov_well, yd_cov_north
Yard        4  West Yard             1,937   0.044     49       5.22   0.10974  Rotor x1                yd_cov_west
Yard        5  Around Pool           3,599   0.083     43       2.39   0.02710  Pop-up x1               yd_cov_pool_east, yd_cov_pool_west
Yard        7  West Fence            1,892   0.043     47       5.11   0.11004  Rotor x1                yd_cov_west_fence
Yard        8  South Fence           1,603   0.037     37       2.22   0.05645  Pop-up x1               yd_cov_south_fence
Yard       10  Block Wall            4,274   0.098     56       2.73   0.02605  Pop-up x1               yd_cov_blockwall
Yard       11  East Yard             1,337   0.031     58       2.78   0.08475  Pop-up x1               yd_cov_patio
----------------------------------------------------------------------------------------------------------------------------------
  Field total:    138,852 ft²  (3.19 acres)
  Yard total:     27,227 ft²  (0.63 acres)
  Grand total:     166,079 ft²  (3.81 acres)
==================================================================================================================================

Notes:
  Sprinkler flow: flow_gpm = rated_gpm * head_count * sqrt(actual_psi / rated_psi)
  Drip flow (†):  total_gpm specified directly in ZONE_HEAD_ASSIGNMENTS
                  Formula: (line_length_ft / emitter_spacing_ft) * num_lines * emitter_gph / 60
  mm/min:         flow_gpm * 40.74 / area_ft2
  Update head_count or total_gpm in ZONE_HEAD_ASSIGNMENTS and re-run to recalibrate.

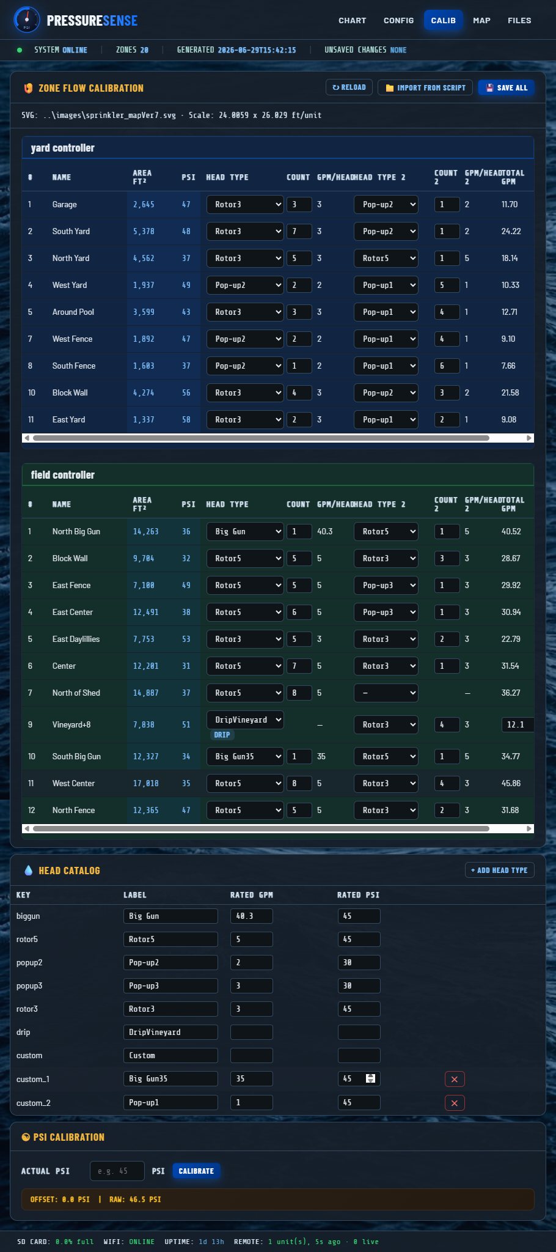
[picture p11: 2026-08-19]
images/PressureSenseCalibration.jpg

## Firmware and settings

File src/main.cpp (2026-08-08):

//*******************************
// Author: Richard Benear 6/7/2026
//*******************************

#include <Arduino.h>
#include "Display.h"
#include <Arduino_JSON.h>
#include <ESPAsyncWebServer.h>
#include <esp_heap_caps.h>
#include <ESPmDNS.h>
#include <ElegantOTA.h>
#include <NTPClient.h>
#include <SPI.h>
#include <WiFi.h>
#include <WiFiUdp.h>
#include <WiFiClientSecure.h>
#include <HTTPClient.h>
#include <time.h>
#include <cmath>	// For fabs()
#include <vector>
#include <map>
#include "FS.h"
#include "SD.h"
#include "secrets.h"
#include "SPIFFS.h"

#define SD_CS D4 				// pin 22	
#define TFT_CS D9 				// pin 20
#define TFT_RST D3 				// pin 21
#define ADC_SAMPLES 10			// number of sensor ADC samples to average
#define SAMPLE_RATE 20000		// PSI sample rate 20 sec in msec
#define ZONES_ALL_OFF_PSI 59	// All Zones off if above this value
#define PRESSURE_WARN_DEVIATION 2.0f	// PSI deviation from zone target to report WARN — matches index.js
#define PRESSURE_ALERT_DEVIATION 4.0f	// PSI deviation from zone target to report HIGH/LOW — matches index.js
#define SENSOR_PIN 2			// Water Pressure sensor on pin GPIO2, ADC, D2
#define TIME_ZONE -3600 * 6		// Mountain Time
#define BUFFER_SIZE 256			// Buffer size for streaming file contents to client in chunks
#define LORA_TX_PIN D5
#define LORA_RX_PIN D1
#define LORA_RESET_PIN TFT_RST
#define LORA_BAUD 115200
#define LORA_MASTER_ADDRESS 10
#define LORA_NETWORK_ID 18
#define LORA_BAND 915000000UL
#define LORA_SPREADING_FACTOR 8
#define LORA_BANDWIDTH 7			// RYLR998 bandwidth code 7 = 125 kHz
#define LORA_CODING_RATE 1			// RYLR998 coding-rate code 1 = 4/5
#define LORA_PREAMBLE 8
#define LORA_TX_POWER_DBM 14
#define LORA_YARD_ADDRESS 1
#define LORA_FIELD_ADDRESS 2

// Since this pressure sensor is designed to run on 5.0 volts but is running
// on 3.3v here, then scale: Pressure Sensor specification:
//    Output 4.5v = 100 PSI
//    Output 0.5v = 0 PSI
//    Slope = 4.0 volts/100 PSI = 0.04 volts/PSI
// Pressure Sensor Scaled:
//    Scaled PSI Range = (3.3v-0.5v)/(5.0v-0.5v) * 100 = 62.2 PSI full range
//    Slope = delta x / delta y: 3.3-0.5-0.5/62.2 = .037 volts/PSI
#define NOMINAL_VOLTS_PER_PSI 0.037
// nominal slope in volts/PSI, based on one point calibration at 48 psi
// measured from analog gauge

// Create AsyncWebServer object on port 80
AsyncWebServer server(80);

// Create an Event Source on /events
AsyncEventSource events("/events");

// Unlike AsyncWebSocket (capped via ws.cleanupClients()), AsyncEventSource
// enforces no client cap at all -- a browser tab that reconnects repeatedly
// (or several tabs/devices left open) can accumulate SSE clients faster
// than the 8s heartbeat's ack-timeout reaps dead ones, eating into the
// device's fixed LWIP socket budget (CONFIG_LWIP_MAX_ACTIVE_TCP = 16) that
// the WS client, HTTP request handling, and outbound weather-API fetches
// all share too. See events.onConnect() below.
#define MAX_SSE_CLIENTS 2  //6
#define MAX_POST_BODY_BYTES 8192
#define HEALTH_LOG_INTERVAL_MS 60000UL

// Create a WebSocket on /ws for the dedicated indoor display
AsyncWebSocket ws("/ws");

HardwareSerial LoRaSerial(1);

// Timer variables
unsigned long lastTime = 0;
unsigned long timerDelay = SAMPLE_RATE;
unsigned long lastSseHeartbeatMillis = 0;

const float adcVoltageScale = 1.032f;
const float sensorCalLowPressure = 30.0f;
const float sensorCalLowVoltage = 1.5f;
const float sensorCalHighPressure = 60.0f;
const float sensorCalHighVoltage = 2.9f;
const float sensorPsiPerVolt = (sensorCalHighPressure - sensorCalLowPressure) /
															 (sensorCalHighVoltage - sensorCalLowVoltage);
const float sensorPressureIntercept = sensorCalLowPressure - (sensorPsiPerVolt * sensorCalLowVoltage);

// Simulation mode — bypasses ADC, injects a fixed PSI value
bool  simMode = false;
float simPsi  = 0.0f;

// variables
float currentPressure = 0.0;
float calibOffset = 0.0;
double ADCvoltage = 0.0;
float rawPressure = 0.0;
int sensorRateSec = 30;
bool schedulesEnabled = true;
String currentLocation  = "";   // cached from site.json's name field, updated on every save
bool   firstReadingDone = false; // guards WS initial-state push on connect

// Set by handleWeatherFetchNow(), consumed by serviceWeatherTask() on its
// next loop() tick -- the actual fetch (a blocking HTTPS call up to 10s)
// must never run directly inside an AsyncWebServer request handler, since
// those execute on the async_tcp task, which IS registered with the 5s
// task watchdog (CONFIG_ESP_TASK_WDT_TIMEOUT_S=5, PANIC=1) and reboots the
// device if a handler blocks past it. Deferring to serviceWeatherTask()
// reuses the same call already proven safe for the daily automatic fetch,
// which runs on loop()'s task instead.
bool weatherFetchNowRequested = false;

bool sdCardLock = false;
unsigned long sdCardLockStartedMillis = 0;

// Last successfully-read SD usage totals, served by /sd-usage whenever
// sdCardLock is held so that handler never touches the SD/SPI bus while a
// logData() write or a /get-data-file stream is mid-transaction elsewhere.
uint64_t cachedSdTotalBytes = 0;
uint64_t cachedSdUsedBytes = 0;

// millis() timestamp of the last periodic ws.textAll(buildSensorUpdateJson())
// broadcast to WS clients (Indoor/Relay units), 0 = none sent yet since boot.
// Surfaced via /sd-usage so the web UI can show remote-unit link health.
unsigned long wsLastBroadcastMillis = 0;
unsigned long lastHealthLogMillis = 0;

// Define NTP Client to get time
WiFiUDP ntpUDP;
NTPClient timeClient(ntpUDP, "pool.ntp.org", TIME_ZONE, 60000);	 // Synchronize time every minute

// Variables to save date and time
String formattedDate = "";
String currentDayStamp = "";
String currentTimeStamp = "";
String currentDailyFilename = "";

IPAddress IPmessage;

static float pressureHistory[CHART_BUFFER_SIZE];
static uint8_t zoneHistory[CHART_BUFFER_SIZE];
static int   historyCount = 0;

// Save reading number on RTC memory
RTC_DATA_ATTR int readingID = 0;

enum LoRaCommand : uint8_t {
	CMD_RELAY_ON = 0x01,
	CMD_RELAY_OFF = 0x02,
	// 0x03 reserved (formerly RUN_TIME, now folded into RELAY_ON)
	CMD_ALL_OFF = 0x04,
	CMD_STATUS_REQUEST = 0x05,
	CMD_RESET = 0x06,
	// 0x08 reserved (formerly ZONE_NAME, now folded into RELAY_ON)
};

enum LoRaResponse : uint8_t {
	RESP_ACK = 0x80,
	RESP_ERROR = 0x81,
	RESP_STATUS = 0x82,
};

static const uint8_t LORA_FLAG_CRC = 0x01;
static const uint8_t LORA_FLAG_RESPONSE_REQUIRED = 0x02;
static const uint8_t LORA_FLAG_TARGET_FIELD = 0x04;
static const uint8_t LORA_ZONE_NAME_MAX_LEN = 20;

String loraLastController = "";
uint8_t loraLastZoneNumber = 0;
bool loraSentIdleAllOff = false;
String loraRxLine = "";

bool zoneDelayPending = false;
unsigned long zoneDelayReadyAt = 0;
int zoneDelayAddress = 0;
uint8_t zoneDelayRelay = 0;
uint16_t zoneDelayRunMinutes = 0;
String zoneDelayController = "";
String zoneDelayName = "";

struct ManualZoneRun {
	bool active;
	String controller;
	uint8_t relay;
	int address;
	unsigned long endMillis;
	uint16_t totalRunMinutes;
	bool isProgram;
	String programLetter;
	int zoneIndex;
	bool delayPending;
	unsigned long delayReadyAt;
	uint8_t pendingRelay;
	int pendingZoneIndex;
	uint16_t pendingRunMinutes;
};

static const uint8_t MAX_MANUAL_ZONE_RUNS = 24;
ManualZoneRun manualZoneRuns[MAX_MANUAL_ZONE_RUNS];

// Weather auto-adjust: how many minutes each (controller,program) has
// actually run today, accumulated once per sample tick in loop(). There is
// no existing per-run duration log to derive this from after the fact (only
// a per-sample CSV row) -- see the implementation plan's water-applied gap.
// RAM-only; consumed and reset to zero by serviceWeatherTask() at day
// rollover. A mid-day reboot loses partial-day accumulation -- accepted,
// low-impact, self-correcting limitation.
// Keyed per-zone (not per-program) so fetchAndApplyWeatherUpdate() can apply
// each zone's own calibrated mm_per_min (calibration.json) to its own
// minutes, rather than one blanket site-wide rate -- the whole point of the
// zone calibration feature. zone.number is already read every sample for
// the display, so no Display.h/Display.cpp change is needed to get it here.
struct WaterAppliedAccumulator {
	String controller;
	int zoneNumber;
	float minutesAppliedToday;
};
static const uint8_t MAX_WEATHER_ZONE_SLOTS = 32;	// generous headroom above the current real zone count (~20)
WaterAppliedAccumulator waterAppliedAccumulators[MAX_WEATHER_ZONE_SLOTS];

// One night's computed result for a single zone -- the new source of truth
// for the weather budget (see weather_state.json's "zones" array). Replaces
// the old single site-wide deficit/adjustPct: each zone's own deficit is
// driven by the shared ET0/rain plus its own applied water, never combined
// with other zones' depths (different zones water different physical areas,
// so their mm values aren't addable -- see the implementation plan).
struct ZoneWeatherResult {
	String controller;
	String program;	// which program this zone belongs to -- carried through only for the program-level log aggregate below
	int zoneNumber;
	double deficitMm;
	int weatherAdjustPct;
	double appliedMm;	// that zone's own applied depth last night -- carried through only for the controller/program-level log aggregates below
};

// weather_log.json's per-day history stays at controller granularity (not
// per-zone -- would balloon the 90-day log for no benefit, since the only
// consumer is the chart's coarse "past 5 days" bars). deficitMm/appliedMm
// are area-weighted averages of that controller's zones (still depths, so
// area-weighting applies); adjustPct is a plain mean (a dimensionless
// ratio, not a depth -- area-weighting doesn't apply to it).
struct ControllerLogAggregate {
	String controller;
	double deficitMm;
	double appliedMm;
	int adjustPct;
};

// Same area-weighted/plain-mean pattern as ControllerLogAggregate, but keyed
// by (controller, program) -- a controller's programs can water disjoint
// physical areas (e.g. field's program A/B split), so each program's
// deficit/applied history must stay independent rather than being blended
// into the controller's single number. Logged nested inside each
// controller's weather_log.json entry (see appendWeatherLogRecord).
struct ProgramLogAggregate {
	String controller;
	String program;
	double deficitMm;
	double appliedMm;
	int adjustPct;
};

String lookupZoneName(String controller, uint8_t relay);
String lookupZoneProgram(String controller, uint8_t relay);
String loadSite();
bool saveSite(JSONVar siteVar);
String loadControllers();
bool saveControllers(JSONVar controllersVar, String filename = "controllers.json");
JSONVar buildSiteVarFromParts(JSONVar siteFields, JSONVar weatherFields);
String buildCombinedZoneDocJson();
int applyRunAdjustments(int baseRunMinutes, int seasonalPct, int weatherPct);
int lookupZoneDelaySeconds(String controller, String program);
int lookupZoneWeatherAdjustPct(String controller, int zoneNumber);
bool isWeatherAutoAdjustEnabled();
double lookupZoneDeficitMm(String controller, int zoneNumber);
bool consumeSkipNextRun(String controller, String program);
String loadWeatherState();
String loadCalibrationData();
String appendWsTypeField(String json, const String &extraFields);
double lookupZoneAreaFt2(String controller, int zoneNumber);
double lookupZoneMmPerMin(String controller, int zoneNumber);
double jsonNumberOr(JSONVar parent, const char *key, double fallback);
String jsonStringOr(JSONVar parent, const char *key, String fallback);
bool jsonBoolOr(JSONVar parent, const char *key, bool fallback);

uint16_t crc16Ccitt(const uint8_t *data, size_t length) {
	uint16_t crc = 0xFFFF;
	for (size_t i = 0; i < length; i++) {
		crc ^= (uint16_t)data[i] << 8;
		for (uint8_t bit = 0; bit < 8; bit++) {
			crc = (crc & 0x8000) ? (crc << 1) ^ 0x1021 : crc << 1;
		}
	}
	return crc;
}

String bytesToHex(const uint8_t *data, size_t length) {
	const char hexDigits[] = "0123456789ABCDEF";
	String out = "";
	out.reserve(length * 2);
	for (size_t i = 0; i < length; i++) {
		out += hexDigits[(data[i] >> 4) & 0x0F];
		out += hexDigits[data[i] & 0x0F];
	}
	return out;
}

int hexNibble(char c) {
	if (c >= '0' && c <= '9') return c - '0';
	if (c >= 'A' && c <= 'F') return c - 'A' + 10;
	if (c >= 'a' && c <= 'f') return c - 'a' + 10;
	return -1;
}

bool hexToBytes(const String &hex, uint8_t *out, size_t maxLength, size_t &outLength) {
	outLength = 0;
	if ((hex.length() % 2) != 0) return false;
	if ((size_t)(hex.length() / 2) > maxLength) return false;

	for (int i = 0; i < hex.length(); i += 2) {
		int high = hexNibble(hex.charAt(i));
		int low = hexNibble(hex.charAt(i + 1));
		if (high < 0 || low < 0) return false;
		out[outLength++] = (uint8_t)((high << 4) | low);
	}
	return true;
}

bool verifyPacketCrc(const uint8_t *packet, size_t length) {
	if (length < 5) return false;
	uint16_t expected = ((uint16_t)packet[length - 2] << 8) | packet[length - 1];
	return crc16Ccitt(packet, length - 2) == expected;
}

void loraSendRawCommand(const String &command, uint16_t settleMs = 120) {
	LoRaSerial.print(command);
	LoRaSerial.print("\r\n");
	Serial.println("[LoRa] > " + command);
	delay(settleMs);
}

void initLoRa() {
	LoRaSerial.begin(LORA_BAUD, SERIAL_8N1, LORA_RX_PIN, LORA_TX_PIN);
	delay(150);

	loraSendRawCommand("AT");
	loraSendRawCommand("AT+ADDRESS=" + String(LORA_MASTER_ADDRESS));
	loraSendRawCommand("AT+NETWORKID=" + String(LORA_NETWORK_ID));
	loraSendRawCommand("AT+BAND=" + String(LORA_BAND));
	loraSendRawCommand("AT+PARAMETER=" + String(LORA_SPREADING_FACTOR) + "," +
	                   String(LORA_BANDWIDTH) + "," +
	                   String(LORA_CODING_RATE) + "," +
	                   String(LORA_PREAMBLE));
	loraSendRawCommand("AT+CRFOP=" + String(LORA_TX_POWER_DBM));
	Serial.println("[LoRa] RYLR998 serial initialized");
}

int loraAddressForController(String controller) {
	controller.trim();
	controller.toLowerCase();
	if (controller == "yard") return LORA_YARD_ADDRESS;
	if (controller == "field") return LORA_FIELD_ADDRESS;
	return -1;
}

const char *loraCommandName(uint8_t command) {
	switch (command) {
		case CMD_RELAY_ON: return "RELAY_ON";
		case CMD_RELAY_OFF: return "RELAY_OFF";
		case CMD_ALL_OFF: return "ALL_OFF";
		case CMD_STATUS_REQUEST: return "STATUS_REQUEST";
		case CMD_RESET: return "RESET";
		default: return "UNKNOWN";
	}
}

uint8_t loraFlagsForAddress(int address, uint8_t flags) {
	if (address == LORA_FIELD_ADDRESS) flags |= LORA_FLAG_TARGET_FIELD;
	return flags;
}

bool sendLoraPacket(int address, uint8_t command, uint8_t relay, uint8_t flags = LORA_FLAG_CRC | LORA_FLAG_RESPONSE_REQUIRED) {
	if (address <= 0) return false;

	uint8_t packet[5];
	packet[0] = command;
	packet[1] = relay;
	packet[2] = loraFlagsForAddress(address, flags);
	uint16_t crc = crc16Ccitt(packet, 3);
	packet[3] = (uint8_t)(crc >> 8);
	packet[4] = (uint8_t)(crc & 0xFF);

	String payload = bytesToHex(packet, sizeof(packet));
	String at = "AT+SEND=" + String(address) + "," + String(payload.length()) + "," + payload;
	loraSendRawCommand(at);
	Serial.printf("[LoRa] sent %s relay %u to addr %d payload %s\n",
	              loraCommandName(command), relay, address, payload.c_str());
	return true;
}
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
void loop() {
	serviceWiFi();
	ElegantOTA.loop();
	ws.cleanupClients();
	pollLoRaResponses();
	serviceManualZoneRuns();
	serviceZoneDelayTimers();
	serviceSdCardLockWatchdog();
	serviceWeatherTask();

	// A dead /events (SSE) client -- e.g. a browser tab whose TCP connection
	// died silently over a sleep/wake cycle -- only gets pruned by AsyncTCP's
	// ~5s ack-timeout on the next time the server actually tries to write to
	// it. Left to the timerDelay-gated sensor broadcast below, that's up to
	// sensorRateSec (often 30s+) between opportunities, letting stale
	// connections pile up during a long idle session against the device's
	// limited concurrent-TCP-connection budget. This fixed, short interval
	// bounds how long a dead connection can sit before being reaped,
	// independent of sensorRateSec.
	if (millis() - lastSseHeartbeatMillis >= 8000) {
		lastSseHeartbeatMillis = millis();
		events.send("hb", "heartbeat", millis());
	}

	if (millis() - lastHealthLogMillis >= HEALTH_LOG_INTERVAL_MS) {
		lastHealthLogMillis = millis();
		Serial.printf(
			"[HEALTH] free=%u min=%u maxAlloc=%u largest=%u WS=%u SSE=%u RSSI=%d sdLock=%d\n",
			ESP.getFreeHeap(),
			ESP.getMinFreeHeap(),
			ESP.getMaxAllocHeap(),
			heap_caps_get_largest_free_block(MALLOC_CAP_8BIT),
			ws.count(),
			events.count(),
			WiFi.RSSI(),
			sdCardLock ? 1 : 0
		);
	}

	if ((millis() - lastTime) > timerDelay) {
		lastTime = millis();

		// Check if it's time to update the daily filename
		updateDailyFilename();

		// Send Events to the client with the Sensor Readings Every 30 seconds
		// events.send("ping", NULL, millis());
		events.send(getSensorReading().c_str(), "new-readings", millis());

		// Broadcast the same reading to all WebSocket clients (indoor display)
		firstReadingDone = true;
		ws.textAll(buildSensorUpdateJson());
		wsLastBroadcastMillis = millis();
		// Manual runs live in a separate mechanism from checkActiveZone() and
		// never appear in sensorUpdate. Broadcast their state on the same
		// cadence so late-joining viewers and natural run-expiry stay in sync.
		ws.textAll(buildManualZoneRunsJson());

		// Build zone info for the display
		ZoneInfo zone;
		zone.number     = String((const char *)readingsJson["Active Zone"]["znumber"]);
		zone.name       = String((const char *)readingsJson["Active Zone"]["zname"]);
		zone.controller = String((const char *)readingsJson["Active Zone"]["controller"]);
		zone.days       = String((const char *)readingsJson["Active Zone"]["days"]);
		zone.start      = String((const char *)readingsJson["Active Zone"]["start"]);
		zone.run        = String((const char *)readingsJson["Active Zone"]["run"]);
		zone.avgPsi     = String((const char *)readingsJson["Active Zone"]["avgpsi"]).toFloat();
		zone.allOff     = (currentPressure >= ZONES_ALL_OFF_PSI);

		// zone.number directly, not gated on zone.allOff -- see the comment
		// in serviceRemoteZoneControl() for why the pressure heuristic can't
		// be trusted to reflect the schedule promptly.
		uint8_t currentZoneNumber = (uint8_t)zone.number.toInt();
		serviceRemoteZoneControl(zone);

		// Weather auto-adjust: accumulate today's actual watering minutes per
		// zone (not program -- see WaterAppliedAccumulator). Schedule-gated
		// only (controller present and not "off") -- previously also gated
		// on the pressure-confirmed allOff heuristic, but that reads "not
		// flowing" for a while after a zone starts whenever pressure hasn't
		// yet fallen from a recent refill, which would undercount real
		// watering during that window.
		if (zone.controller.length() > 0 && zone.controller != "off") {
			int waterSlot = findOrCreateWaterAccumulatorSlot(zone.controller, (int)currentZoneNumber);
			if (waterSlot >= 0) {
				waterAppliedAccumulators[waterSlot].minutesAppliedToday += sensorRateSec / 60.0f;
			}
		}

		// Weather auto-adjust: same per-tick crediting as the scheduled path
		// above, but for Manual Program runs -- manualZoneRuns[] is populated
		// by startManualProgramRun()/serviceManualZoneRuns() and never known to
		// checkActiveZone(), so it needs its own loop here rather than being
		// folded into the block above. Gated on manualZoneRuns[].active/
		// isProgram/delayPending directly (relay-commanded state), not the
		// site-wide pressure sensor -- same reasoning as the scheduled path.
		// Ad hoc single-zone manual runs (isProgram == false) are
		// intentionally excluded -- out of scope for this feature.
		for (uint8_t i = 0; i < MAX_MANUAL_ZONE_RUNS; i++) {
			if (!manualZoneRuns[i].active || !manualZoneRuns[i].isProgram) continue;
			if (manualZoneRuns[i].delayPending) continue; // relay is physically off during the inter-zone gap

			int waterSlot = findOrCreateWaterAccumulatorSlot(manualZoneRuns[i].controller, (int)manualZoneRuns[i].relay);
			if (waterSlot >= 0) {
				waterAppliedAccumulators[waterSlot].minutesAppliedToday += sensorRateSec / 60.0f;
			}
		}

		// Rolling display history — shift left when full, append newest sample.
		if (historyCount < CHART_BUFFER_SIZE) {
			pressureHistory[historyCount] = currentPressure;
			zoneHistory[historyCount] = currentZoneNumber;
			historyCount++;
		} else {
			memmove(pressureHistory, pressureHistory + 1,
			        (CHART_BUFFER_SIZE - 1) * sizeof(float));
			memmove(zoneHistory, zoneHistory + 1,
			        (CHART_BUFFER_SIZE - 1) * sizeof(uint8_t));
			pressureHistory[CHART_BUFFER_SIZE - 1] = currentPressure;
			zoneHistory[CHART_BUFFER_SIZE - 1] = currentZoneNumber;
		}

		// Alert when live PSI is >4 below the zone's configured average.
		// zone.avgPsi > 0 already implies an active zone (checkActiveZone()
		// only populates it for the schedule's current zone) -- dropped the
		// !zone.allOff gate, which could suppress a real deviation right as
		// a zone starts, before pressure has fallen from a recent refill.
		String alertZoneName = "";
		if (zone.avgPsi > 0.0f && currentPressure < zone.avgPsi - PRESSURE_ALERT_DEVIATION) {
			alertZoneName = zone.name;
		}

		getTimeStamp(currentDayStamp, currentTimeStamp);
		updateTftDisplay(currentPressure, IPmessage, WiFi.RSSI(), zone,
		                 currentTimeStamp, pressureHistory, zoneHistory, historyCount,
		                 (int)(timerDelay / 1000), alertZoneName);
		logData();
		Serial.println(ADCvoltage);
	}
	delay(100);
}

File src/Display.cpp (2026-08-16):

#include "Display.h"
#include <cmath>   // fabsf, roundf

// ── LovyanGFX hardware config ─────────────────────────────────────────────────

class LGFX : public lgfx::LGFX_Device {
    lgfx::Panel_ILI9488 _panel;
    lgfx::Bus_SPI       _bus;

public:
    LGFX(void) {
        {
            auto cfg = _bus.config();
            cfg.spi_host    = SPI2_HOST;
            cfg.spi_mode    = 0;
            cfg.freq_write  = 8000000;
            cfg.freq_read   = 4000000;
            cfg.spi_3wire   = false;
            cfg.use_lock    = true;
            cfg.dma_channel = SPI_DMA_CH_AUTO;
            cfg.pin_sclk    = 19;   // D8
            cfg.pin_mosi    = 18;   // D10
            cfg.pin_miso    = 20;   // D9  (readable = false)
            cfg.pin_dc      = 16;   // D6
            _bus.config(cfg);
            _panel.setBus(&_bus);
        }
        {
            auto cfg = _panel.config();
            cfg.pin_cs       = 17;   // D7
            cfg.pin_rst      = 21;   // D3
            cfg.pin_busy     = -1;
            cfg.panel_width  = 320;
            cfg.panel_height = 480;
            cfg.readable     = false;
            cfg.invert       = false;
            cfg.rgb_order    = false;
            cfg.dlen_16bit   = false;
            cfg.bus_shared   = true;
            _panel.config(cfg);
        }
        setPanel(&_panel);
    }
};

static LGFX tft;

// ── Color palette (RGB565) — mirrors the web UI CSS variables ─────────────────
// Updated alongside the site-wide contrast & typography pass (brighter
// secondary text, amber section headings, brighter status colors) so the
// on-device panel and the web dashboard read as the same product.
//
//  Web hex    →  R5  G6  B5  → RGB565
//  #060a10   →   0   2   2  → 0x0042   body background
//  #0d1117   →   1   4   2  → 0x0882   header / card background
//  #0a1420   →   1   5   4  → 0x0924   gauge panel background  (NEW)
//  #061420   →   0   5   4  → 0x0124   zone card background    (NEW)
//  #0d1a2a   →   1   6   5  → 0x08C5   stat card background    (NEW)
//  #3f658d   →   8  25  17  → 0x4331   borders, grid lines
//  #9eb3c4   →  19  44  24  → 0x9D98   dim labels                   (was #546c81)
//  #7ec1ff   →  15  48  31  → 0x7E1F   mid values / meta text       (was #60a5fa/#87bef2)
//  #f2f7fc   →  30  61  31  → 0xF7BF   primary value text           (was #e8f4fd)
//  #0d6efd   →   1  27  31  → 0x0B7F   accent blue
//  #f4b740   →  30  45   8  → 0xF5A8   section headings (amber)     (was #c7c419 yellow-green)
//  #fbbf24   →  31  47   4  → 0xFDE4   amber / warning               (was #f59e0b)
//  #10ce42   →   2  22   5  → 0x1668   green / OK
//  #f87171   →  31  28  14  → 0xFB8E   red / error                   (was #ef4444)
//  #1a1200   →   3   9   0  → 0x1900   amber pill background   (NEW)
//  #0a2a1a   →   1  10   3  → 0x0943   status OK pill bg       (NEW)
//  #2a0a0a   →   5   2   1  → 0x2801   status ERR pill bg      (NEW)
//  #1a1500   →   3  10   0  → 0x1A00   status WARN pill bg     (NEW)

static const uint16_t C_BG_BODY   = 0x0042;
static const uint16_t C_BG_HEADER = 0x0882;
static const uint16_t C_BG_GAUGE  = 0x0924;   // gauge panel — blue-tinted dark
static const uint16_t C_BG_ZONE   = 0x0124;   // zone card  — deeper blue-green
static const uint16_t C_BG_STAT   = 0x08C5;   // mini stat cards
static const uint16_t C_BORDER    = 0x4331;
static const uint16_t C_DIM       = 0x9D98;
static const uint16_t C_BLUE_HI   = 0x7E1F;
static const uint16_t C_HI        = 0xF7BF;
static const uint16_t C_HEAD      = 0xF5A8;
static const uint16_t C_ACCENT    = 0x0B7F;
static const uint16_t C_AMBER     = 0xFDE4;
static const uint16_t C_RED       = 0xFB8E;
static const uint16_t C_GREEN     = 0x1668;
static const uint16_t C_AMBER_BG  = 0x1900;   // pill bg for amber alerts
static const uint16_t C_OK_BG     = 0x0943;   // pill bg for OK status
static const uint16_t C_ERR_BG    = 0x2801;   // pill bg for ERR status
static const uint16_t C_WARN_BG   = 0x1A00;   // pill bg for WARN status

// ── Layout (480 × 320, landscape rotation) ────────────────────────────────────
//
//  y=0..31    : header bar
//  y=32       : horizontal separator
//  y=33..157  : gauge panel      (C_BG_GAUGE)
//  y=158..196 : stat card row    (two mini cards, C_BG_STAT)
//  y=197..286 : zone info card   (C_BG_ZONE)
//  y=287..319 : today strip      (C_BG_HEADER)
//
//  x=0..151   : left panel
//  x=152      : vertical separator
//  x=153..178 : Y-axis label column  (26 px)
//  x=179      : Y-axis line
//  x=180..474 : chart data area      (295 px, 5 px right gutter)
//  y=285      : X-axis line
//  y=286..319 : time label / today strip row

static const int HDR_H     = 32;
static const int LPANEL_W  = 152;
static const int SEP_X     = 152;
static const int YAXIS_X   = 179;
static const int PLOT_X    = 180;
static const int PLOT_Y    = 33;
static const int PLOT_BOT  = 285;
static const int PLOT_H    = PLOT_BOT - PLOT_Y;   // 252 px
static const int PLOT_RIGHT_GUTTER = 5;
static const int PLOT_W    = 480 - PLOT_X - PLOT_RIGHT_GUTTER; // 295 px

// Left panel row boundaries
static const int GAUGE_TOP  = PLOT_Y;      // 33
static const int GAUGE_BOT  = 157;
static const int STAT_TOP   = 158;
static const int STAT_BOT   = 196;
static const int ZONE_TOP   = 197;
static const int ZONE_BOT   = 286;
static const int TODAY_TOP  = 287;
static const int TODAY_BOT  = 319;
static const int TIME_LABEL_Y = 311;

// ── Gauge geometry ─────────────────────────────────────────────────────────────
static const int   GAUGE_CX    = 71;
static const int   GAUGE_CY    = 88;    // absolute y from top of screen
static const int   GAUGE_R_OUT = 50;
static const int   GAUGE_R_IN  = 42;   // 8 px thick ring
static const float GAUGE_START = 225.0f;
static const float GAUGE_SWEEP = 270.0f;

static const float PSI_MAX     = 70.0f;
static const float PSI_ALL_OFF = 59.0f;
static const int   PLOT_DOT_R  = 2;

// ── Helpers ────────────────────────────────────────────────────────────────────

static int psiToY(float psi) {
    if (psi < 0.0f)    psi = 0.0f;
    if (psi > PSI_MAX) psi = PSI_MAX;
    return PLOT_BOT - (int)(psi / PSI_MAX * (float)PLOT_H);
}

static uint16_t psiColor(float psi, bool allOff) {
    if (allOff || psi >= PSI_ALL_OFF) return C_GREEN;
    if (psi >= 35.0f) return C_ACCENT;
    if (psi >= 25.0f) return C_AMBER;
    return C_RED;
}

// Mirrors the -60/-75dBm good/fair break points typical of Wi-Fi signal
// meters; -87dBm has been observed in the field as a barely-usable link
// (see the TCP keepalive comment in main.cpp).
static uint16_t rssiColor(int rssi) {
    if (rssi >= -60) return C_GREEN;
    if (rssi >= -75) return C_AMBER;
    return C_RED;
}
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

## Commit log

2026-07-26 fixed day-rollover bug and updated README
    [Display.cpp, main.cpp]
2026-07-26 fixed Reset Zoom button
2026-08-08 added Weather State JSON support for App and improved flash usage safety
    [partitions.csv]
2026-08-11 added Relay Delay and % Adjust to monitor
